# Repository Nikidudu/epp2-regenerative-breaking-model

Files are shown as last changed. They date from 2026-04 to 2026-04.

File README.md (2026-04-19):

# Regenerative Braking System

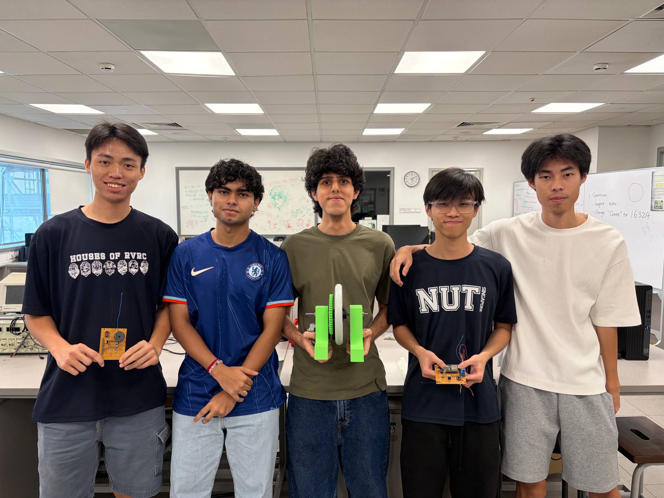
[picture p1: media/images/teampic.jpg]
Team Picture
 

## Overview
Regenerative braking is a key technology in electric vehicles that recovers kinetic energy during deceleration and converts it into usable electrical energy. Instead of dissipating energy as heat, this system improves overall efficiency, extends driving range, and reduces mechanical wear.

This project demonstrates a small-scale regenerative braking system that converts rotational kinetic energy into electrical energy using a DC motor as a generator, with energy stored for later use.

## Design Goals & Objectives
The objective of this project is to design a regenerative braking system capable of converting kinetic energy into electrical energy during deceleration and storing it efficiently. The system aims to achieve an energy recovery efficiency of at least 50%, operate within a 12–24V range, and safely manage current flow using a controlled power electronic interface. Additional goals include ensuring system safety, minimising energy losses, and maintaining reliable operation under repeated braking conditions.

## System Architecture
The system operates by switching a PMDC motor from motoring mode (electrical → mechanical) to generating mode (mechanical → electrical) during braking. The rotational inertia of the system drives the motor, producing electrical energy which is then conditioned and stored.

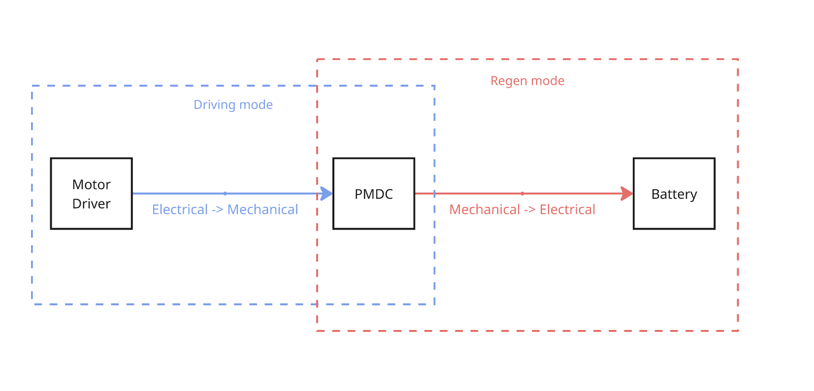
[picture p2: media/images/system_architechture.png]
System Architecture
 

## Mechanical Design
The mechanical system consists of a rotating wheel directly coupled to a PMDC motor. During braking, the kinetic energy of the rotating wheel is transferred to the motor shaft, causing it to act as a generator.

For detailed design and considerations:
- [Mechanical Design](docs/mechanical.md)

## Electrical Design
The electrical subsystem switches the motor from driving mode or regenerative mode. During driving mode, users may control the acceleration of the motor. During regenerative mode, the AC voltage is rectified and boosted into a capacitor for storage.

For full circuit design and explanation:
- [Electrical Design](docs/electrical.md)

## Software
A PID loop is used to control the PWM of the DC-DC converter, ensuring output voltage remains constant towards the battery. Other software include the swtiching mechanism and driving PWM.

- [Software Design](docs/software.md)

## Results
In Progress: The project aims to

- Measure energy saved from regenerative breaking
- Successfuly store energy in energy storing element
- Noticeable mechanical resistance corresponding to regenerative braking

Full Results:

- [Results and Analysis](docs/results.md)

## Final Project

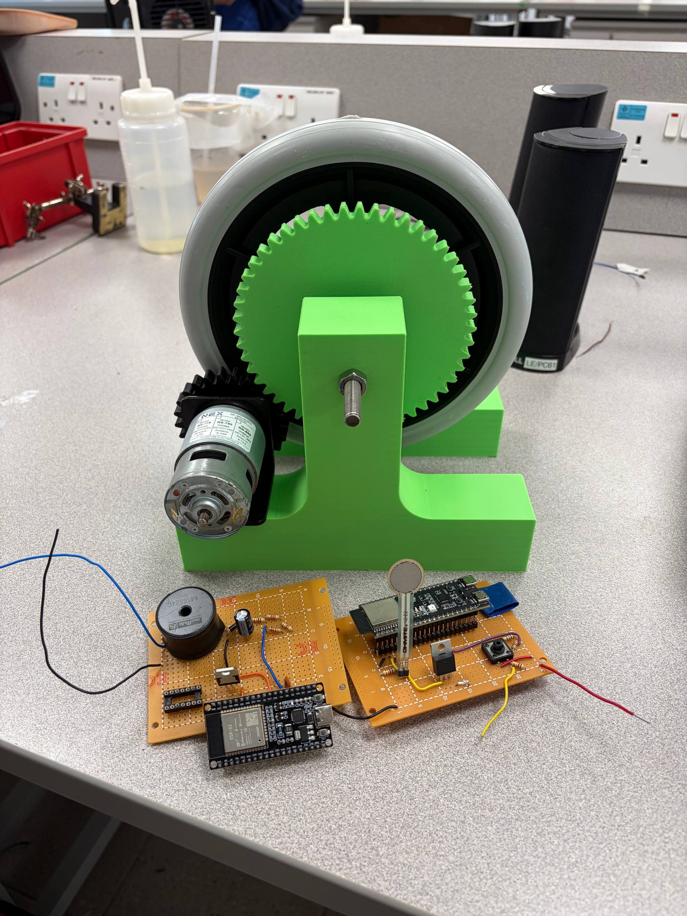
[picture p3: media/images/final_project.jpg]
final project
 

## Future Improvements

- Our system had some siginficant issues when connecting a low resistance load, namely the DC-DC converter will go into DCM mode, rendering our PID useless. A higher PWM freqency could be used to improve this.
- Our mechanical design was tested with 6V instead of the rated 12V, due to saftey concerns, a more stable build is needed to test with higher speeds.
- We had an issue with a wire burning up with no apparent reason, further analysis needed.
- There was a lack of noticable breaking of the wheel. The wheel span for 20 seconds without regen, and around 18 seconds with regen. This may be due to the use of a high resistance load, causing less current being able to flow.

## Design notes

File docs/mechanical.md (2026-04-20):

# Mechanical Design

## 1. Design Objectives

The mechanical system was designed to provide stable rotational support for the flywheel while enabling sufficient momentum to be stored in the wheel to observe regenerative breaking.

The key objectives were:
- To provide stable support for the rotating wheel  
- To minimise frictional losses during rotation  
- To ensure effective coupling between the wheel and generator  
- To reduce the speed of the wheel by using a correct gear ratio
- To allow enough momentum for a stable back emf to be produced.

## 2. Overall Design Description

The system consists of a rotating wheel mounted on a shaft, which is mechanically coupled to a motor acting as a generator. The generated electrical energy is then processed by the boost converter circuit.

Energy flow in the system can be summarised as:

**Mechanical Energy (wheel rotation) → Gear Reduction → Generator/Motor**

The wheel stores kinetic energy, which is partially recovered during regenerative braking when the generator applies an opposing torque.

## 3. Key Components and Design Choices

### 3.1 Flywheel

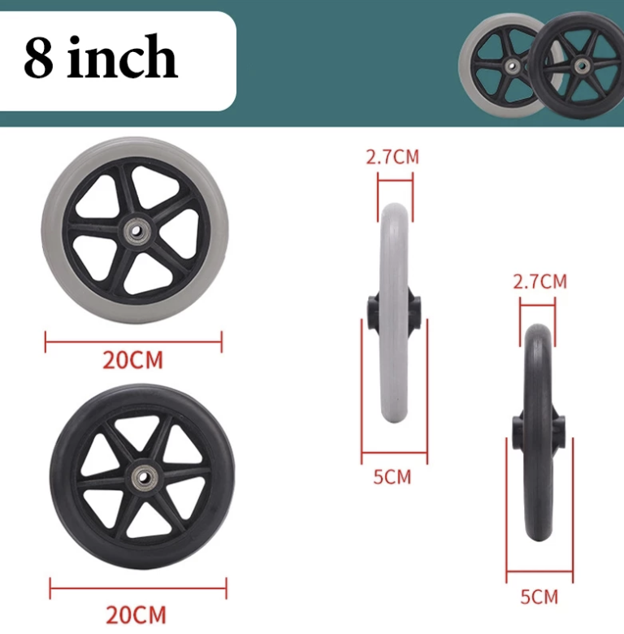
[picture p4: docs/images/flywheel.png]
flywheel


A 8-inch wheelchair wheel was used as the flywheel element in the system. The primary function of the flywheel is to store kinetic energy, which can then be converted into electrical energy during braking.

However, due to its relatively low mass, the flywheel has low rotational inertia. This limits the total amount of recoverable energy and reduces the observable effect of regenerative braking.

The wheel also came with a bearing attached to the centre bore, allowing for free motion between the shaft and wheel.

### 3.2 Shaft and Gears

shaft and gears

- The wheel is mounted onto a threaded rod that is locked in to the supports via 8 inch nuts.
- One gear is connected directly to the wheel, while the other is connected towards the motor. The gear ratio used is 1:2, with PLA material andpress fitted on the wheel and motor.
- A motor bracket was used to secure the motor into place, using 6mm threaded inserts and screws into the supports.

### 3.3 Structural Frame

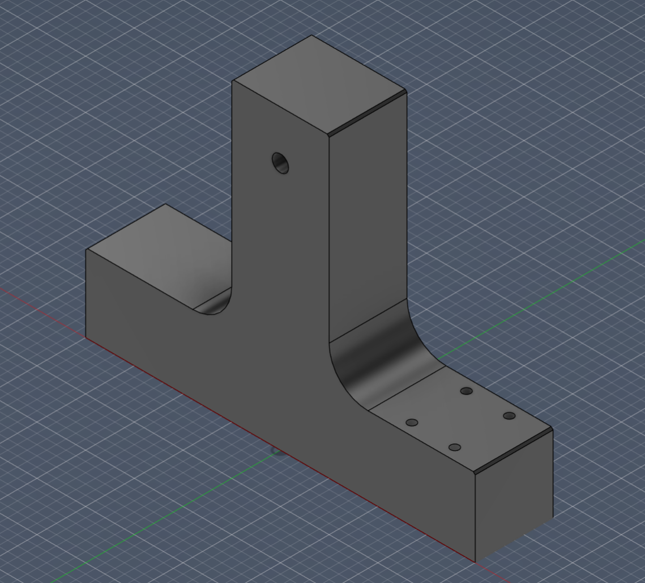
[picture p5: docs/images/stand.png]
stand


The structural frame was constructed using a PLA material and were fully 3d-printed. While sufficient for low-speed testing, the frame lacked rigidity. 

This resulted in:
- High vibrations at higher rotational speeds  
- Safety concerns when operating at the intended 12 V  
- Restriction of testing to 6 V operation  

## 4. System Performance Analysis

The mechanical design directly influenced the experimental results.

- The wheel spin time was observed to be approximately 20 seconds (without regenerative braking) this proved that there was minimal friction between the bearking and the supports, this allowed us to carry enough momentum and observe regenerative braking results if there were any.  
- The machine underwent heavy vibrating in higher RPMS. As a result, a human operator had to hold down the build while the wheel was spinning at high rpms, and we were capped at 6V operation.
- The gears fit nicely with each other, with no gear interfearence observed. However, loud sounds were produced due to using spur gears.

## 5. Limitations of Current Design

The current mechanical design has several limitations:

- **Low structural rigidity**, preventing safe high-speed operation  
- **Low flywheel inertia**, limiting energy storage capacity  
- **Higher friction losses** due to basic support structure  
- **Lack of safety enclosure**, restricting testing conditions  

These limitations contributed to the reduced performance observed in the system.

## 6. Improvements and Future Work

Several improvements can be made to enhance the mechanical performance:

- Use a **heavier flywheel** to increase rotational inertia and energy storage  
- Construct a **more rigid frame** (e.g., aluminium or reinforced structure)  
- Add a **protective enclosure** to enable safe high-speed testing  
- Ensure secure mounting of all components to minimise vibration  

These improvements would allow the system to operate at higher speeds and significantly enhance the effectiveness of regenerative braking.

## 7. Summary

The mechanical system successfully enabled rotational motion and energy transfer; however, its performance was limited by structural and design constraints.

While functional at low voltage, the design requires further refinement to achieve efficient and safe operation under higher loads, particularly for demonstrating effective regenerative braking.

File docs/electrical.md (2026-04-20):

# Electrical System

## 1. Design Objectives

The electrical system was designed to enable energy conversion, voltage regulation, and controlled regenerative braking.

The key objectives were:
- To convert mechanical energy into electrical energy using a generator  
- To regulate the generated voltage to a stable output of 6.6 V  
- To implement a closed-loop control system using a PID controller  
- To safely manage current and voltage within system limits  
- To interface with sensors and actuators for real-time control  

## 2. System Overview

The electrical system consists of two main subsystems:

1. **Acceleration and Braking Controller** – A system to control breaking and acceleration 
2. **Power Conversion** – A boost converter steps up and regulates the generated voltage with a closed-loop control.

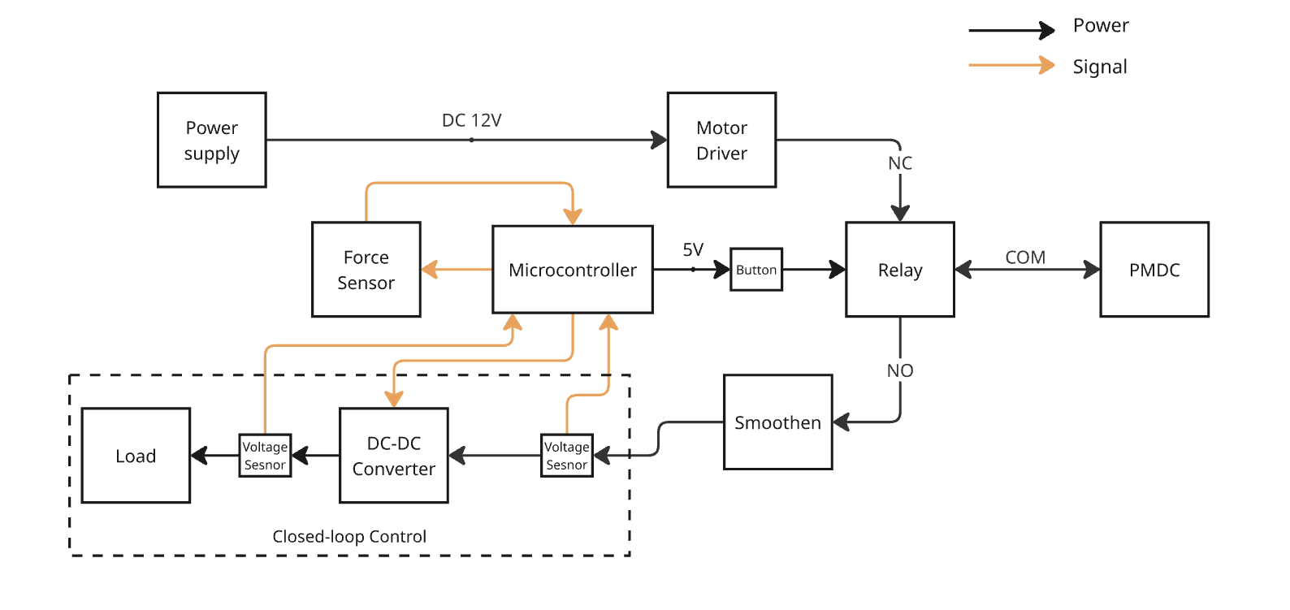
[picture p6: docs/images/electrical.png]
System Overview


## 3. Key Components and Design Choices

## 3.1 Acceleration and Braking Controller (SSM)

### 3.1.1 Generator/DC Motor

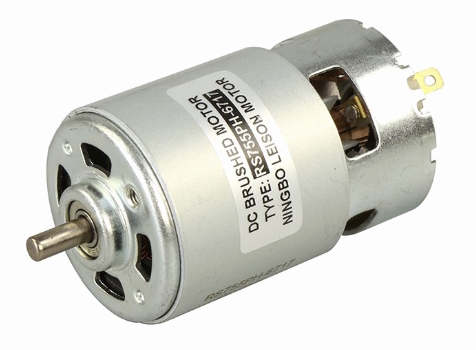
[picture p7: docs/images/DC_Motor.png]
DC motor


A RS-775-R 12V-24V DC motor is used as the generator and motor to convert rotational energy into electrical energy via electromagnetic induction and vice versa. The motor was chosen due to its high RPM capabilities with low torque.

Since generated voltage is proportional to rotational speed, this would be suitable as the high RPMs allow us to observe these effects greatly. 

This dependency directly affects the performance of the system, especially at lower operating voltages.

### 3.1.2 Force sensor

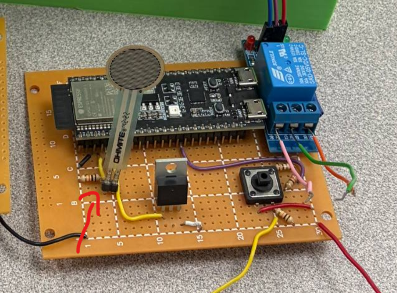
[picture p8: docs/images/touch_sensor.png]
force sensor


A Round Force Sensor (FSR402) was used to simulate the accalerator pedal in cars. It works by increasing the resistance as more force is applied. 

The connections are as follows:
- Connected to a 3.3V high output pin in the esp32
- Pulldown resistor on output to reduce noise and floating voltage
- Input to a standard GPIO analog pin

### 3.1.3 Relay and Button Switching

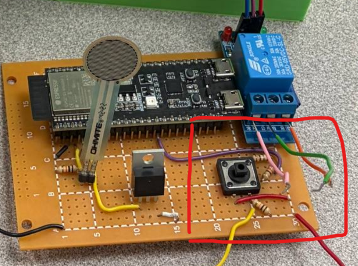
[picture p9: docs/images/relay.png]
relay


A standard relay with 5V switching was used to change between the modes of braking and non-braking. The relay switches to NO when the signal pin is put to ground, and NC otherwise.

The connections are as follows:
- The relay is grounded via a resistor to prevent current surge and floating voltages, this leaves the default state at NC, where this is in non-braking mode
- One end of the button is put to the 5V high from the arduino
- When the button is pressed, the signal wire from the relay is set to a 5V high, switching the relay circuit from non-braking to braking mode.
- A voltage devider is used to split the voltage of 5V to 3.3V to allow the button status to be read digitally as well

## 3.2 Power conversion

### 3.2.1 Boost Converter

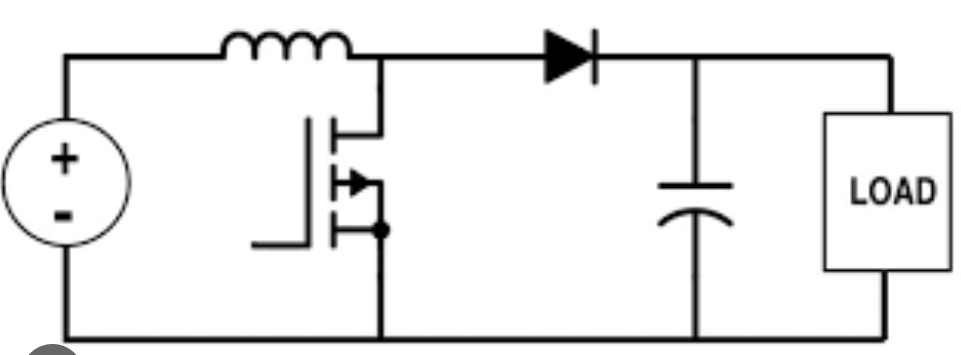
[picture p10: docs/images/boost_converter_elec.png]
boost converter


A standard boost converter was made to step up the variable input voltage from the generator to a stable output voltage.

The converter operates using:
- A MOSFET controlled by PWM  
- An inductor for energy storage  
- A diode and capacitor for output smoothing  

By adjusting the duty cycle of the PWM signal, the output voltage can be controlled.

### 3.2.2 Voltage Sensing (ADC System)

The ESP32 ADC operates in continuous sampling mode to measure:
- Output voltage (Vout)  
- Input voltage (Vin)  

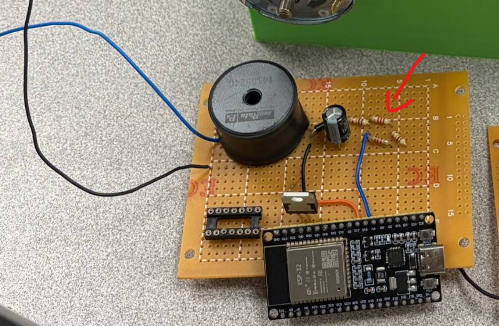
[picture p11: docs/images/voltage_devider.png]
voldev


To measure these voltages, a voltage divider was used to scale the voltage readings to the 3.3V analog input in the esp32.

Key features:
- High-frequency sampling (~50 kHz)  
- Averaging of multiple samples to reduce noise  
- Calibration using eFuse-based correction  
- Voltage divider scaling to measure higher voltages  

This enables accurate real-time feedback for the control system.

### 3.2.3 PWM Control (LEDC Module)

The ESP32 LEDC module generates a PWM signal to control the boost converter.

- Frequency: 4 kHz  
- Resolution: 13-bit  
- Duty cycle range: 0 to 7500  

The duty cycle determines how much energy is transferred through the converter:
- Higher duty cycle → higher output voltage  
- Lower duty cycle → lower output voltage  

## 4. Control System (PID Controller)

A PID controller is implemented to regulate the output voltage to a target of **6.6 V**.

The control law is:

- Proportional term responds to present error  
- Integral term accumulates past error  
- Derivative term predicts future error  

The controller continuously:
1. Measures output voltage  
2. Computes error relative to target  
3. Updates PID terms  
4. Adjusts PWM duty cycle  

## 5. System Behaviour and Performance

The system successfully maintained a stable output voltage of approximately **6.6 V for 15 seconds**, demonstrating effective closed-loop control.

However, performance was affected under certain conditions:

- When connected to a low-resistance load, the converter entered **Discontinuous Conduction Mode (DCM)**  
- In DCM, the system dynamics changed, reducing the effectiveness of the PID controller  
- This resulted in reduced stability and control accuracy  

Additionally:
- Limited input voltage (due to low rotational speed) restricted overall system performance  
- High resistance loads reduced current flow, limiting braking effectiveness  

## 6. Electrical Issues Encountered

### 6.1 DC-DC Converter Instability
The converter became unstable under heavy load conditions due to transition into DCM. This caused the PID controller to behave unpredictably.

### 6.2 Wire Overheating
A wire was observed to burn during operation, indicating excessive current or insufficient wire rating.

Possible causes include:
- Undersized wire gauge  
- Lack of current limiting  
- Unexpected current spikes  

### 6.3 Limited Power Transfer
The system exhibited limited braking performance due to low current flow, which reduced electromagnetic braking torque.

## 7. Limitations of Current Design

- Operation limited to **6 V instead of 12 V**  
- PID tuning not optimised for different operating modes (CCM vs DCM)  
- Lack of current protection mechanisms  
- Inefficient power transfer under certain load conditions  
- Limited switching frequency affecting converter performance  

## 8. Improvements and Future Work

- Increase PWM switching frequency to reduce DCM operation  
- Implement **current sensing and protection** (e.g., shunt resistor, fuse)  
- Optimise PID tuning for different operating conditions  
- Improve component selection (MOSFET, inductor, wiring) for higher current handling  
- Enable safe operation at **12 V** to improve performance  
- Add filtering or compensation to improve stability  

## 9. Summary

The electrical system successfully demonstrated energy conversion and voltage regulation using a closed-loop control system.

While stable voltage output was achieved, performance was limited by converter dynamics, load conditions, and hardware constraints. Further optimisation of both control and hardware design is required to fully realise effective regenerative braking.

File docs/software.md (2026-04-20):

# Software

The software portion of this project can be divided into two main components:

- Small State Machine (User Input & System Control)
- Boost Converter Feedback Loop (Voltage Regulation)

## Small State Machine

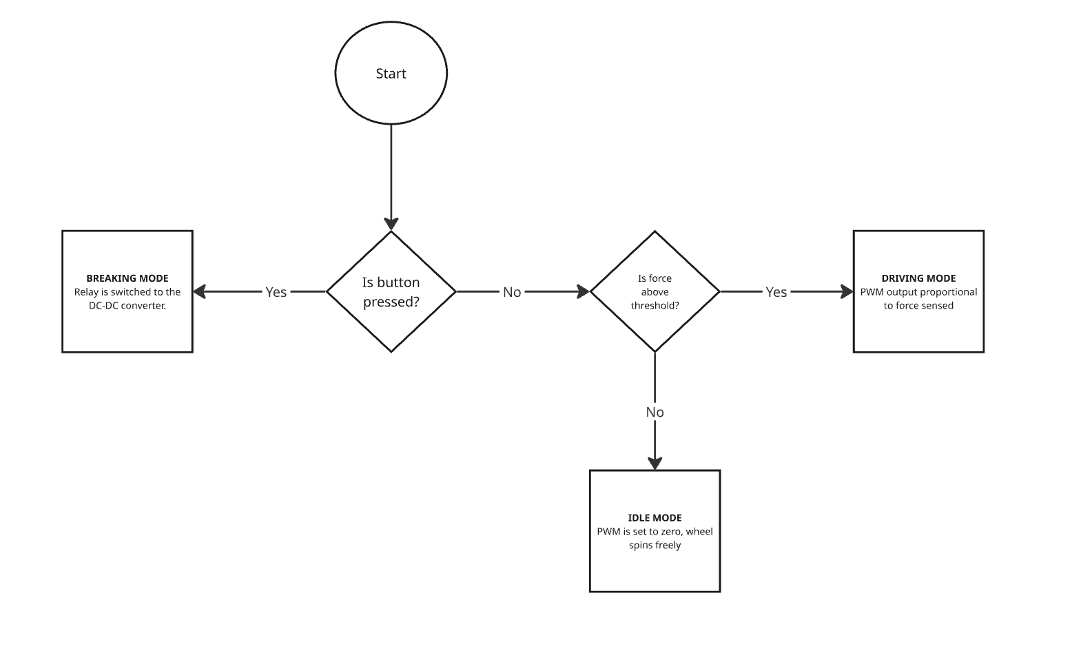
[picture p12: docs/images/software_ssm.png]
ssm


The small state machine is responsible for controlling when regenerative braking is active, based on user input and force detection.

A force sensor is continuously read using the ADC, and its value is mapped to a PWM signal. This PWM signal controls the level of braking applied.

A button input is used to toggle the braking system:
- When the button is pressed, braking is **disabled**
- When the button is not pressed, braking is **enabled**

The system operates in three main states:

1. **Driving and Acceleration**
    - Activated when the measured force is above the predefined threshold and active breaking is not enabled
    - PWM is proportional to force applied on sensor
    - The system accelerates

2. **Idle / No Braking**
   - Activated when the measured force is below a predefined threshold and active braking is not enabled  
   - PWM output is set to 0 
   - The system does not apply any braking force 

3. **Active Braking**
   - Activated when the button is pressed, regardless of the force sensor input
   - PWM output is set to zero
   - A relay and digital output are activated to engage the braking circuitry into the boost converter

This simple logic ensures that braking only occurs when required, preventing unnecessary energy dissipation and improving system control.

## Boost Converter Feedback Loop

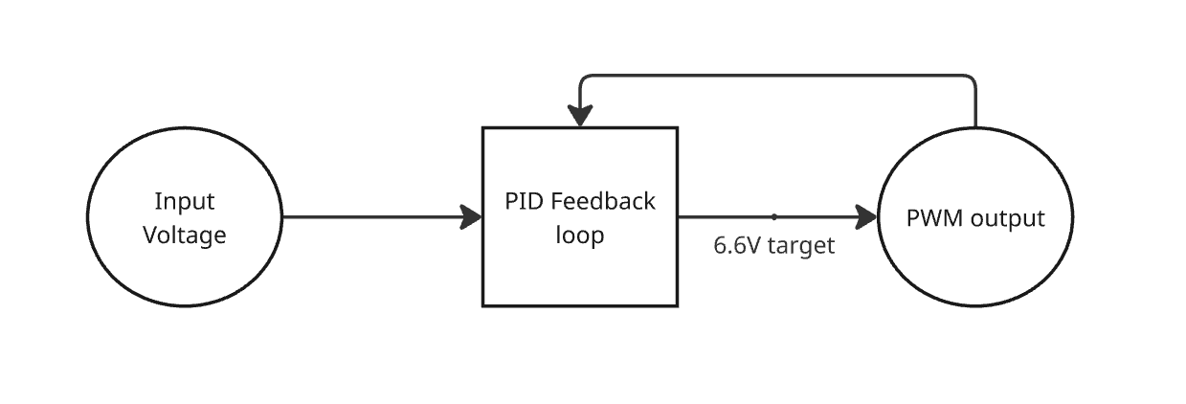
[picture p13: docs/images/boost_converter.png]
boost


The boost converter feedback loop is implemented on the ESP32 using a PID controller to regulate the output voltage.

### Signal Acquisition
- Two ADC channels are used:
  - One measures the **output voltage (Vout)**
  - One measures the **input voltage (Vin)**
- The ADC operates in continuous sampling mode at high frequency
- Raw ADC values are averaged and calibrated to obtain accurate voltage readings
- A voltage divider scaling factor is applied to reconstruct the actual voltage

### PID Control System

The system regulates the output voltage to a target of **6.6 V** using a PID controller.

- **Proportional term (P):** Responds to instantaneous voltage error  
- **Integral term (I):** Accumulates past error to eliminate steady-state offset  
- **Derivative term (D):** Predicts future error based on rate of change  

The control loop performs the following steps:
1. Measure output voltage  
2. Compute error between measured voltage and target voltage  
3. Update PID terms (with integral windup limiting)  
4. Adjust PWM duty cycle accordingly  

The PWM signal is generated using the ESP32 LEDC module and drives the boost converter switching element.

### Control Features and Safeguards

- **Integral windup protection:** Limits the integral term to prevent instability  
- **Duty cycle clamping:** Ensures PWM stays within safe bounds  
- **Noise floor handling:** Resets control when voltage is too low  
- **Dynamic timestep (dt):** Improves accuracy of derivative and integral calculations  

### System Behaviour

- When output voltage is below 6.6 V, the controller increases PWM duty cycle to boost voltage  
- When output voltage exceeds 6.6 V, the controller reduces duty cycle  
- The system continuously adjusts in real time to maintain a stable output voltage  

## Summary

The software integrates a high-level control system (state machine) with a low-level control loop (PID-regulated boost converter).  

- The **state machine** determines *when* braking should occur  
- The **PID controller** determines *how much* energy is transferred and regulates voltage  

Together, they enable controlled and stable regenerative braking operation.

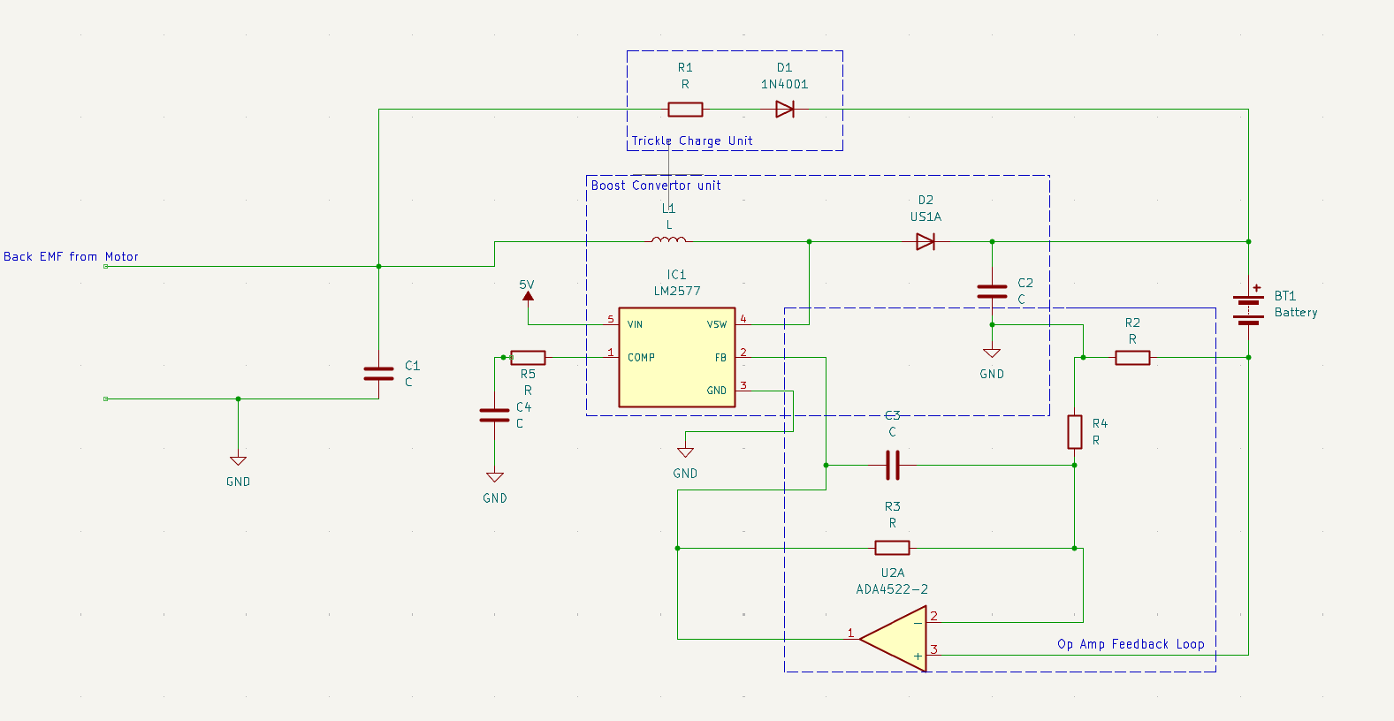
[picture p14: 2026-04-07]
hardware/electrical/images/Img_Paper_Design_Charging_Unit.png

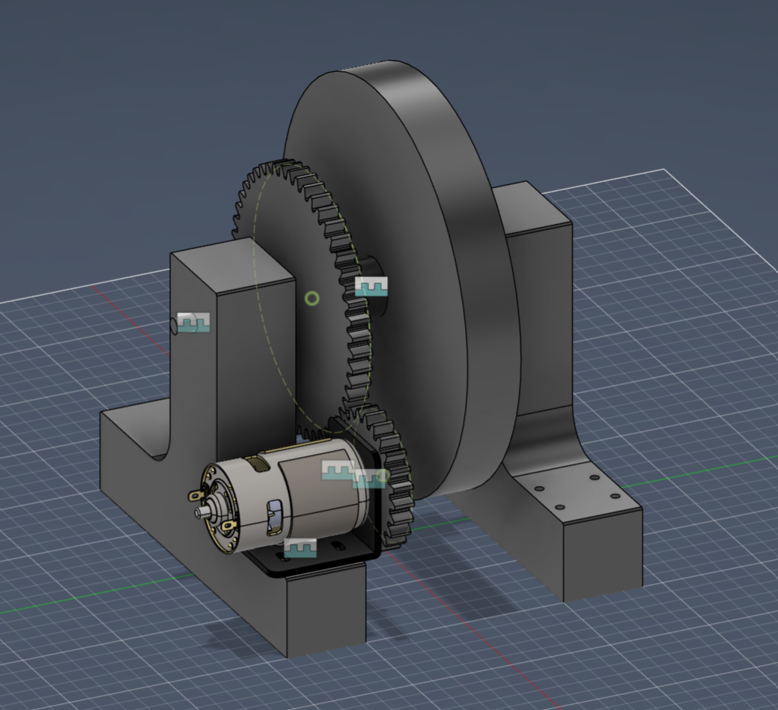
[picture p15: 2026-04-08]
hardware/mechanical/images/final_assemby_CAD.png

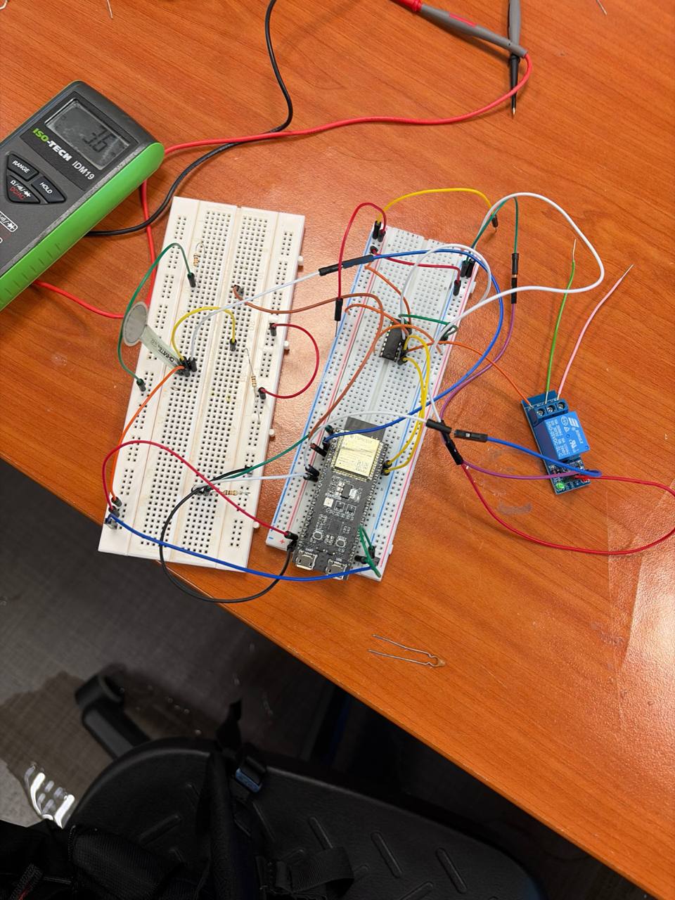
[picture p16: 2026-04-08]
hardware/electrical/images/accelerator_and_relay.jpg

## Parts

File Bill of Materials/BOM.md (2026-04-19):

| Item | Quantity | Price |
| ---- | --- | ----- |
|  RS-775-R DC Motor | 1 | 11.54 |
| Bracket for motor	| 1 | 5.51 |
| Stainless Steel Threaded Rod Screw | 1 | 7.33 |
| 8 inch wheel | 1 | 9.9 |
|  | **Total** | **34.28** |

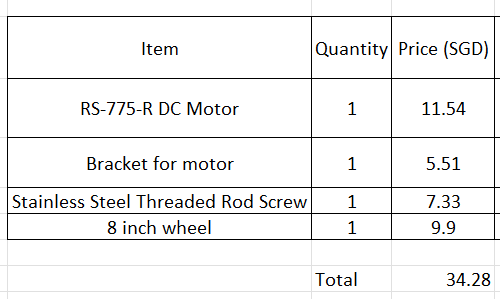
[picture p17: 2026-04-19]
Bill of Materials/BOM.png

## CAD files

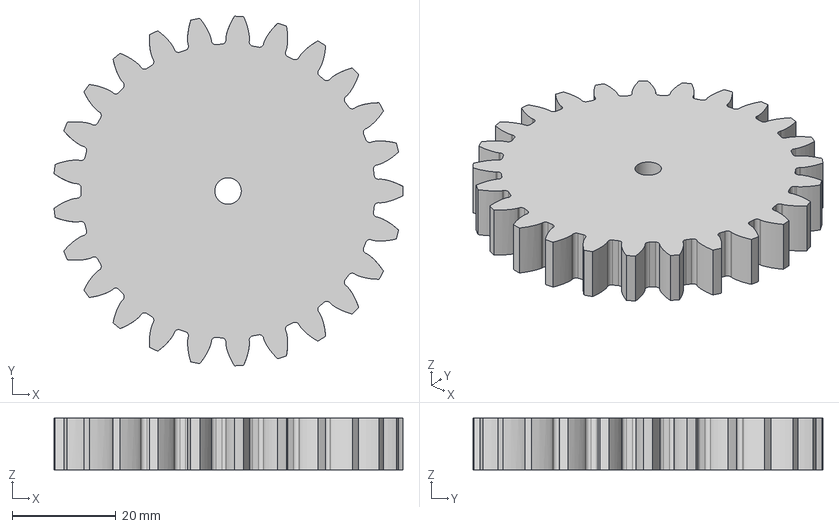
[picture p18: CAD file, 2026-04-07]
hardware/mechanical/cad/smallgeartight.step
67.3 x 67.5 x 10.0 mm

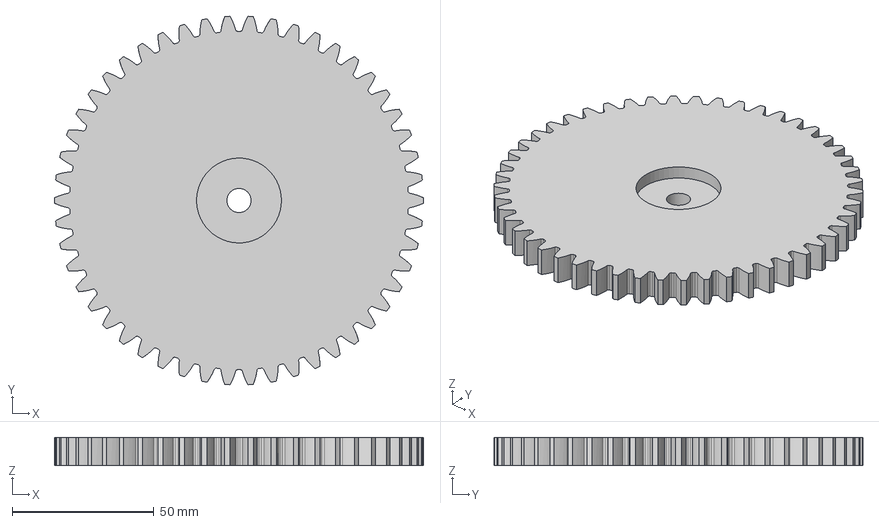
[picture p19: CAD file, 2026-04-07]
hardware/mechanical/cad/Gear BIG2.step
130.0 x 129.9 x 10.0 mm

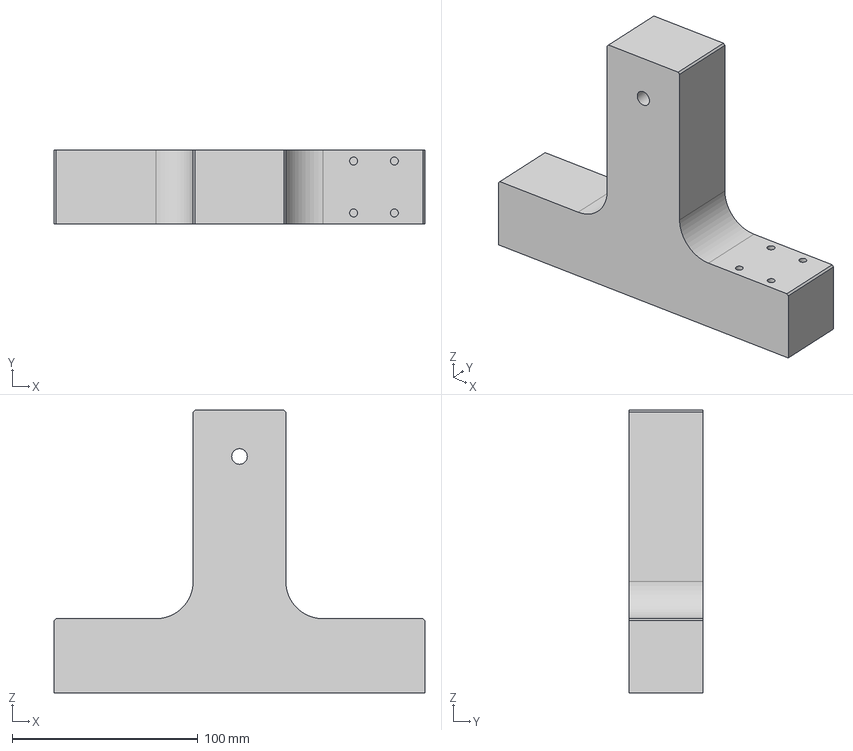
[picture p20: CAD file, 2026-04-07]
hardware/mechanical/cad/Stand 2.step
200.0 x 40.0 x 152.4 mm

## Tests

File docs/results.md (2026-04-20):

# Results and Analysis

## 1. Overview of Results
The prototype demonstrated successful operation, maintaining a steady back voltage of **6.6 V** for approximately **15 seconds** under controlled conditions. This indicates that the regenerative system is capable of stable energy conversion within the tested parameters.

## 2. Key Experimental Results
- The system maintained a back steady back voltage of **6.6 V for 15 seconds**
- Without regenerative braking, the wheel spun for approximately **20 seconds**
- With regenerative braking, the wheel spun for approximately **18 seconds**
- Testing was conducted at **6 V instead of the rated 12 V** due to safety concerns
- PID was tuned sufficiently until no oscilation was found from the varying back voltage.

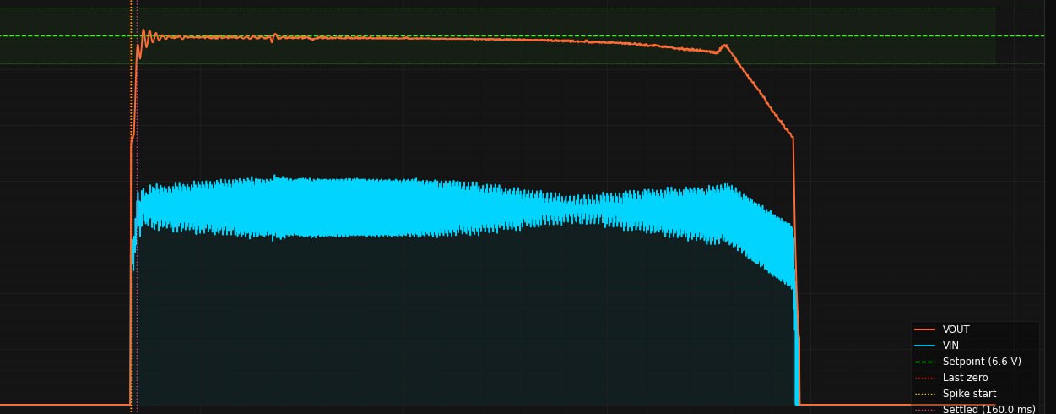
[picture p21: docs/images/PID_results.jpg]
PID results


## 3. Analysis of System Performance
The relatively small reduction in wheel spin time (from 20 s to 18 s) suggests that the regenerative braking effect was minimal. This is likely due to the use of a **high-resistance load**, which limited current flow and therefore reduced the electromagnetic braking torque.

Additionally, operating the system at **6 V instead of 12 V** reduced the rotational speed and back EMF generated, further limiting the observable performance of the regenerative braking system.

## 4. Identified Issues and Technical Explanation

### 4.1 DC-DC Converter Instability
When connected to a low-resistance load, the DC-DC converter entered **Discontinuous Conduction Mode (DCM)**, rendering the PID controller ineffective. This occurs because the system dynamics change significantly in DCM, making the existing PID tuning unsuitable. Increasing the PWM switching frequency could help maintain **Continuous Conduction Mode (CCM)** and improve system stability.

### 4.2 Mechanical Limitations
The system was only tested at **6 V** due to safety concerns regarding the structural integrity of the setup. At this lower voltage, the system operates at reduced speed, limiting both energy generation and braking performance. A more robust mechanical design is required to safely test the system at its intended **12 V operating condition**.

### 4.3 Electrical Fault (Wire Overheating)
A wire was observed to burn during operation, indicating a possible **overcurrent condition** or insufficient wire gauge. This suggests that the current exceeded safe limits, highlighting the need for proper current rating calculations and protective components such as **fuses or current limiting mechanisms**.

### 4.4 Limited Braking Effect
The minimal difference in stopping time indicates weak regenerative braking performance. This is likely due to the **high-resistance load**, which restricts current flow. Since braking torque is proportional to current, increasing current flow (e.g., by reducing load resistance or improving power handling capability) would result in stronger braking.

## 5. Evaluation Against Objectives
While the system successfully demonstrated **voltage regulation**, it did not achieve significant braking performance. This suggests that the electrical control aspect of the system is functional, but further optimisation of load conditions, control strategy, and mechanical design is required to fully achieve the objectives of effective regenerative braking.

## 6. Improvements and Future Work
- Increase PWM switching frequency to reduce the likelihood of DCM operation  
- Redesign the mechanical structure to safely support **12 V testing**  
- Use appropriately rated wires and implement **overcurrent protection**  
- Optimise load resistance to allow higher current flow and improve braking torque  
- Retune the PID controller for different operating modes (CCM vs DCM)

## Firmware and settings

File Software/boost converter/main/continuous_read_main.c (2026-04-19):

/*
 * SPDX-FileCopyrightText: 2021-2022 Espressif Systems (Shanghai) CO LTD
 *
 * SPDX-License-Identifier: Apache-2.0
 */
#include "esp_adc/adc_cali.h"
#include "esp_adc/adc_cali_scheme.h"
#include <string.h>
#include <stdio.h>
#include "sdkconfig.h"
#include "esp_log.h"
#include "freertos/FreeRTOS.h"
#include "esp_err.h"
#include "driver/ledc.h"
#include "esp_timer.h"
#include "freertos/task.h"
#include <math.h>
#include "freertos/semphr.h"
#include "esp_adc/adc_continuous.h"

#define EXAMPLE_ADC_UNIT                    ADC_UNIT_1  
#define _EXAMPLE_ADC_UNIT_STR(unit)         #unit
#define EXAMPLE_ADC_UNIT_STR(unit)          _EXAMPLE_ADC_UNIT_STR(unit)
#define EXAMPLE_ADC_CONV_MODE               ADC_CONV_SINGLE_UNIT_1
#define EXAMPLE_ADC_ATTEN                   ADC_ATTEN_DB_12
#define EXAMPLE_ADC_BIT_WIDTH               SOC_ADC_DIGI_MAX_BITWIDTH

#if CONFIG_IDF_TARGET_ESP32 || CONFIG_IDF_TARGET_ESP32S2
#define EXAMPLE_ADC_OUTPUT_TYPE             ADC_DIGI_OUTPUT_FORMAT_TYPE1
#define EXAMPLE_ADC_GET_CHANNEL(p_data)     ((p_data)->type1.channel)
#define EXAMPLE_ADC_GET_DATA(p_data)        ((p_data)->type1.data)
#else
#define EXAMPLE_ADC_OUTPUT_TYPE             ADC_DIGI_OUTPUT_FORMAT_TYPE2
#define EXAMPLE_ADC_GET_CHANNEL(p_data)     ((p_data)->type2.channel)
#define EXAMPLE_ADC_GET_DATA(p_data)        ((p_data)->type2.data)
#endif
#define ADC_NOISE_FLOOR_MV  200
#define EXAMPLE_READ_LEN                    256
/*pwm config */
#define LEDC_TIMER              LEDC_TIMER_0
#define LEDC_MODE               LEDC_HIGH_SPEED_MODE
#define LEDC_OUTPUT_IO          25 // Define the output GPIO
#define LEDC_CHANNEL            LEDC_CHANNEL_0
#define LEDC_DUTY_RES           LEDC_TIMER_13_BIT // Set duty resolution to 13 bits
#define LEDC_DUTY               (4096) // Set duty to 50%. (2 ** 13) * 50% = 4096
#define LEDC_FREQUENCY          (4000) // Frequency in Hertz. Set frequency at 4 kHz

#define SMALL_RESISTANCE 2200
#define BIG_RESISTANCE 10000
                
#define i_limit  1.0f // Integral windup limit based on max duty cycle and Ki
#define PID_KP        56.0f
#define PID_KI        1.0f
#define PID_KD        2.67f
#define VOUT  6.6f      // Volts
#define DUTY_MAX        7500.0f
#define DUTY_MIN        0.0f

#if CONFIG_IDF_TARGET_ESP32
static adc_channel_t channel[2] = {ADC_CHANNEL_6, ADC_CHANNEL_7}; //GPIO 34, 35
#else
static adc_channel_t channel[2] = {ADC_CHANNEL_2, ADC_CHANNEL_3};
#endif

static TaskHandle_t s_task_handle;
static const char* TAG = "EXAMPLE";
static adc_cali_handle_t cali_handle = NULL;

static void example_ledc_init(void)
{
    // Prepare and then apply the LEDC PWM timer configuration
    ledc_timer_config_t ledc_timer = {
        .speed_mode       = LEDC_MODE,
        .duty_resolution  = LEDC_DUTY_RES,
        .timer_num        = LEDC_TIMER,
        .freq_hz          = LEDC_FREQUENCY,  // Set output frequency at 4 kHz
        .clk_cfg          = LEDC_AUTO_CLK
    };
    ESP_ERROR_CHECK(ledc_timer_config(&ledc_timer));

    // Prepare and then apply the LEDC PWM channel configuration
    ledc_channel_config_t ledc_channel = {
        .speed_mode     = LEDC_MODE,
        .channel        = LEDC_CHANNEL,
        .timer_sel      = LEDC_TIMER,
        .intr_type      = LEDC_INTR_DISABLE,
        .gpio_num       = LEDC_OUTPUT_IO,
        .duty           = 0, // Set duty to 0%
        .hpoint         = 0
    };
    ESP_ERROR_CHECK(ledc_channel_config(&ledc_channel));
}

static bool IRAM_ATTR s_conv_done_cb(adc_continuous_handle_t handle, const adc_continuous_evt_data_t *edata, void *user_data)
{
    BaseType_t mustYield = pdFALSE;
    //Notify that ADC continuous driver has done enough number of conversions
    vTaskNotifyGiveFromISR(s_task_handle, &mustYield);

    return (mustYield == pdTRUE);
}

static void continuous_adc_init(adc_channel_t *channel, uint8_t channel_num, adc_continuous_handle_t *out_handle)
{
    adc_continuous_handle_t handle = NULL;

    adc_continuous_handle_cfg_t adc_config = {
        .max_store_buf_size = 1024,
        .conv_frame_size = EXAMPLE_READ_LEN,
    };
    ESP_ERROR_CHECK(adc_continuous_new_handle(&adc_config, &handle));

    adc_continuous_config_t dig_cfg = {
        .sample_freq_hz = 50 * 1000,
        .conv_mode = EXAMPLE_ADC_CONV_MODE,
        .format = EXAMPLE_ADC_OUTPUT_TYPE,
    };

    adc_digi_pattern_config_t adc_pattern[SOC_ADC_PATT_LEN_MAX] = {0};
    dig_cfg.pattern_num = channel_num;
    for (int i = 0; i < channel_num; i++) {
        adc_pattern[i].atten = EXAMPLE_ADC_ATTEN;
        adc_pattern[i].channel = channel[i] & 0x7;
        adc_pattern[i].unit = EXAMPLE_ADC_UNIT;
        adc_pattern[i].bit_width = EXAMPLE_ADC_BIT_WIDTH;

        ESP_LOGI(TAG, "adc_pattern[%d].atten is :%"PRIx8, i, adc_pattern[i].atten);
        ESP_LOGI(TAG, "adc_pattern[%d].channel is :%"PRIx8, i, adc_pattern[i].channel);
        ESP_LOGI(TAG, "adc_pattern[%d].unit is :%"PRIx8, i, adc_pattern[i].unit);
    }
    dig_cfg.adc_pattern = adc_pattern;
    ESP_ERROR_CHECK(adc_continuous_config(handle, &dig_cfg));

    *out_handle = handle;
}

void app_main(void)
{   
    float parallel_voltage_pd_multiplier = (float)(SMALL_RESISTANCE + BIG_RESISTANCE) / SMALL_RESISTANCE; // Calculate the multiplier for parallel voltage measurement
    esp_err_t ret;
   // esp_log_set_vprintf(NULL);
    uint32_t ret_num = 0;

    uint8_t result[EXAMPLE_READ_LEN] = {0};

    float Voutput = VOUT;

    memset(result, 0xcc, EXAMPLE_READ_LEN);

    adc_cali_line_fitting_config_t cali_config = {
        .unit_id = EXAMPLE_ADC_UNIT,
        .atten = EXAMPLE_ADC_ATTEN,
        .bitwidth = EXAMPLE_ADC_BIT_WIDTH,
    };

    float pid_integral   = 0.0f;
    float pid_prev_measurement = 0.0f;
    float dt = 0.001f;
    int   targetDutyCycle           = 0;
    int64_t last_loop_time = esp_timer_get_time();
    int64_t current_time;

    example_ledc_init();
    esp_err_t retefuse = adc_cali_create_scheme_line_fitting(&cali_config, &cali_handle);
    if (retefuse == ESP_OK) {
        ESP_LOGI(TAG, "Calibration Success!");
    } else {
        ESP_LOGW(TAG, "Calibration not supported or eFuse not burnt.");
    }
    s_task_handle = xTaskGetCurrentTaskHandle();

    adc_continuous_handle_t handle = NULL;
    continuous_adc_init(channel, sizeof(channel) / sizeof(adc_channel_t), &handle);

    adc_continuous_evt_cbs_t cbs = {
        .on_conv_done = s_conv_done_cb,
    };
    ESP_ERROR_CHECK(adc_continuous_register_event_callbacks(handle, &cbs, NULL));
    ESP_ERROR_CHECK(adc_continuous_start(handle));
    ESP_LOGI(TAG, "i_limit: %.2f", i_limit);
    uint32_t sum_raw_ch6 = 0;
    uint32_t sum_raw_ch7 = 0;
    while (1) {

        /**
         * This is to show you the way to use the ADC continuous mode driver event callback.
         * This `ulTaskNotifyTake` will block when the data processing in the task is fast.
         * However in this example, the data processing (print) is slow, so you barely block here.
         *
         * Without using this event callback (to notify this task), you can still just call
         * `adc_continuous_read()` here in a loop, with/without a certain block timeout.
         */
        ulTaskNotifyTake(pdTRUE, portMAX_DELAY);

       // char unit[] = EXAMPLE_ADC_UNIT_STR(EXAMPLE_ADC_UNIT);

        while (1) {
            ret = adc_continuous_read(handle, result, EXAMPLE_READ_LEN, &ret_num, 0);
            if (ret == ESP_OK) {
                uint32_t sum_raw_ch6 = 0;   // moved inside, removed stale sum_raw
                uint32_t sum_raw_ch7 = 0;

                current_time = esp_timer_get_time();
                dt = (current_time - last_loop_time) / 1000000.0f;
                last_loop_time = current_time;
                int sample_count_ch6 = 0;
                int sample_count_ch7 = 0;
                int calibrated_voltage     = 0;
                int calibrated_voltage_ch7 = 0;

                for (int i = 0; i < ret_num; i += SOC_ADC_DIGI_RESULT_BYTES) {
                    adc_digi_output_data_t *p = (adc_digi_output_data_t*)&result[i];
                    uint8_t ch = EXAMPLE_ADC_GET_CHANNEL(p);

                    if (ch == channel[0]) {
                        sum_raw_ch6 += EXAMPLE_ADC_GET_DATA(p);
                        sample_count_ch6++;
                    } else if (ch == channel[1]) {
                        sum_raw_ch7 += EXAMPLE_ADC_GET_DATA(p);
                        sample_count_ch7++;
                    }
                }
                if (sample_count_ch6 > 0) {
                    adc_cali_raw_to_voltage(cali_handle, sum_raw_ch6 / sample_count_ch6, &calibrated_voltage);
                }
                if (sample_count_ch7 > 0) {
                    adc_cali_raw_to_voltage(cali_handle, sum_raw_ch7 / sample_count_ch7, &calibrated_voltage_ch7);
                }

                float node_voltage;
                float input_voltage;
                float pid_output;
               // float targetDutyCycle;
                if (calibrated_voltage < ADC_NOISE_FLOOR_MV) {
                    calibrated_voltage = 0;
                    node_voltage = 0.0f;
                    pid_integral = 0.0f; // Reset integral term if voltage is at noise floor
                    pid_prev_measurement = 0.0f; // Reset previous measurement
                    targetDutyCycle = 0; // Set to max duty cycle to try to increase voltage
                    pid_output = 0.0f;

                } else {
                    node_voltage = ((calibrated_voltage ) * parallel_voltage_pd_multiplier / 1000.0);
                    float error = Voutput - node_voltage;
                    pid_integral += error * dt;
                    
                    if (pid_integral >  i_limit) pid_integral =  i_limit;
                    if (pid_integral < -i_limit) pid_integral = -i_limit;
                    
                    float derivative = (pid_prev_measurement - node_voltage) / dt;
                    pid_prev_measurement = node_voltage;
                    pid_output     = PID_KP * error + PID_KI * pid_integral + PID_KD * derivative;
                    targetDutyCycle += pid_output;
                    if (targetDutyCycle > DUTY_MAX) targetDutyCycle = DUTY_MAX;
                    if (targetDutyCycle < DUTY_MIN) targetDutyCycle = DUTY_MIN;



                    //targetDutyCycle = round((1.0-(node_voltage / Voutput))*8191.0); // Calculate duty cycle based on voltage
                    
                }
                input_voltage = (calibrated_voltage_ch7 < ADC_NOISE_FLOOR_MV)? 0.0f   : (calibrated_voltage_ch7 * parallel_voltage_pd_multiplier / 1000.0f);
                                   
                ESP_ERROR_CHECK(ledc_set_duty(LEDC_MODE, LEDC_CHANNEL, (int)targetDutyCycle)); 
                ESP_ERROR_CHECK(ledc_update_duty(LEDC_MODE, LEDC_CHANNEL));
               // ESP_LOGI(TAG, "Calibrated Voltage: %d mV , Node Voltage: %.2f V, with PWM Duty Cycle: %d", calibrated_voltage, node_voltage, targetDutyCycle);
                ESP_LOGI(TAG, "TIME: %"PRIu64" VIN: %.2f V, VOUT: %.2f V, PWM: %d, PID: %.2f, I: %.2f",current_time, input_voltage, node_voltage, (int)targetDutyCycle, pid_output, pid_integral);
               vTaskDelay(1);
            } else if (ret == ESP_ERR_TIMEOUT) {
                //We try to read `EXAMPLE_READ_LEN` until API returns timeout, which means there's no available data
                break;
            }
        }
    }

    ESP_ERROR_CHECK(adc_continuous_stop(handle));
    ESP_ERROR_CHECK(adc_continuous_deinit(handle));
}

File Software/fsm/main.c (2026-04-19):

#include <stdio.h>
#include <string.h>
#include "freertos/FreeRTOS.h"
#include "freertos/task.h"
#include "driver/gpio.h"
#include "driver/ledc.h"
#include "esp_adc/adc_oneshot.h"
#include "esp_adc/adc_cali.h"
#include "esp_adc/adc_cali_scheme.h"
#include "esp_log.h"

/* ── Pin definitions ───────────────────────────────────────────────── */
#define FORCE_SENSOR_PIN    ADC_CHANNEL_3   // GPIO4  on ESP32 = ADC1_CH3
#define PWM_OUTPUT_PIN      2               // GPIO2
#define DIGITAL_OUT_PIN     1               // GPIO1
#define BUTTON_OUT_PIN      18              // GPIO18
#define BUTTON_IN_PIN       17              // GPIO17
#define RELAY_PIN           16              // GPIO16

/* ── Thresholds / constants ────────────────────────────────────────── */
#define FORCE_THRESHOLD     1000            // raw ADC counts (0–4095)
#define ADC_MAX_RAW         4095
#define PWM_MAX_DUTY        255             // 8-bit PWM  (0–255)

/* ── LEDC (PWM) config ─────────────────────────────────────────────── */
#define LEDC_TIMER          LEDC_TIMER_0
#define LEDC_MODE           LEDC_LOW_SPEED_MODE
#define LEDC_CHANNEL        LEDC_CHANNEL_0
#define LEDC_DUTY_RES       LEDC_TIMER_8_BIT   // 8-bit → 0-255
#define LEDC_FREQUENCY      5000                // 5 kHz

static const char *TAG = "FORCE_CTRL";

/* ──────────────────────────────────────────────────────────────────── */
/*  Helpers                                                             */
/* ──────────────────────────────────────────────────────────────────── */

/** Linear map, identical to Arduino map() */
static inline int map_value(int x, int in_min, int in_max, int out_min, int out_max)
{
    return (x - in_min) * (out_max - out_min) / (in_max - in_min) + out_min;
}

/** Clamp an int between lo and hi */
static inline int constrain_value(int x, int lo, int hi)
{
    if (x < lo) return lo;
    if (x > hi) return hi;
    return x;
}

/* ──────────────────────────────────────────────────────────────────── */
/*  Peripheral initialisation                                           */
/* ──────────────────────────────────────────────────────────────────── */

static void gpio_init(void)
{
    /* outputs */
    gpio_config_t out_cfg = {
        .pin_bit_mask = (1ULL << DIGITAL_OUT_PIN) |
                        (1ULL << BUTTON_OUT_PIN)  |
                        (1ULL << RELAY_PIN),
        .mode         = GPIO_MODE_OUTPUT,
        .pull_up_en   = GPIO_PULLUP_DISABLE,
        .pull_down_en = GPIO_PULLDOWN_DISABLE,
        .intr_type    = GPIO_INTR_DISABLE,
    };
    gpio_config(&out_cfg);

    /* inputs */
    gpio_config_t in_cfg = {
        .pin_bit_mask = (1ULL << BUTTON_IN_PIN),
        .mode         = GPIO_MODE_INPUT,
        .pull_up_en   = GPIO_PULLUP_DISABLE,
        .pull_down_en = GPIO_PULLDOWN_DISABLE,
        .intr_type    = GPIO_INTR_DISABLE,
    };
    gpio_config(&in_cfg);

    /* match Arduino setup() initial states */
    gpio_set_level(DIGITAL_OUT_PIN, 0);   // LOW
    gpio_set_level(BUTTON_OUT_PIN,  1);   // HIGH
    gpio_set_level(RELAY_PIN,       1);   // HIGH
}

static void ledc_pwm_init(void)
{
    ledc_timer_config_t timer = {
        .speed_mode      = LEDC_MODE,
        .duty_resolution = LEDC_DUTY_RES,
        .timer_num       = LEDC_TIMER,
        .freq_hz         = LEDC_FREQUENCY,
        .clk_cfg         = LEDC_AUTO_CLK,
    };
    ESP_ERROR_CHECK(ledc_timer_config(&timer));

    ledc_channel_config_t ch = {
        .speed_mode = LEDC_MODE,
        .channel    = LEDC_CHANNEL,
        .timer_sel  = LEDC_TIMER,
        .intr_type  = LEDC_INTR_DISABLE,
        .gpio_num   = PWM_OUTPUT_PIN,
        .duty       = 0,
        .hpoint     = 0,
    };
    ESP_ERROR_CHECK(ledc_channel_config(&ch));
}

static adc_oneshot_unit_handle_t adc_init(void)
{
    adc_oneshot_unit_handle_t handle;

    adc_oneshot_unit_init_cfg_t unit_cfg = {
        .unit_id  = ADC_UNIT_1,
        .ulp_mode = ADC_ULP_MODE_DISABLE,
    };
    ESP_ERROR_CHECK(adc_oneshot_new_unit(&unit_cfg, &handle));

    adc_oneshot_chan_cfg_t chan_cfg = {
        .atten    = ADC_ATTEN_DB_12,        // up to ~3.1 V, matches ADC_11db
        .bitwidth = ADC_BITWIDTH_12,        // 0–4095
    };
    ESP_ERROR_CHECK(adc_oneshot_config_channel(handle, FORCE_SENSOR_PIN, &chan_cfg));

    return handle;
}

/* ──────────────────────────────────────────────────────────────────── */
/*  PWM helper                                                          */
/* ──────────────────────────────────────────────────────────────────── */

static void set_pwm(int duty)   // duty: 0–255
{
    ESP_ERROR_CHECK(ledc_set_duty(LEDC_MODE, LEDC_CHANNEL, (uint32_t)duty));
    ESP_ERROR_CHECK(ledc_update_duty(LEDC_MODE, LEDC_CHANNEL));
}

/* ──────────────────────────────────────────────────────────────────── */
/*  Main task  (replaces loop())                                        */
/* ──────────────────────────────────────────────────────────────────── */

void app_main(void)
{
    gpio_init();
    ledc_pwm_init();
    adc_oneshot_unit_handle_t adc_handle = adc_init();

    bool break_flag = true;

    while (1) {
        /* ── 1. Read force sensor ──────────────────────────────────── */
        int analog_reading = 0;
        ESP_ERROR_CHECK(adc_oneshot_read(adc_handle, FORCE_SENSOR_PIN, &analog_reading));

        /* ── 2. Map ADC → PWM duty (0-4095 → 0-255) ───────────────── */
        int pwm_value = map_value(analog_reading, 0, ADC_MAX_RAW, 0, PWM_MAX_DUTY);
        pwm_value = constrain_value(pwm_value, 0, PWM_MAX_DUTY);

        /* ── 3. Button → relay + break_flag ───────────────────────── */
        if (gpio_get_level(BUTTON_IN_PIN) == 1) {
            gpio_set_level(RELAY_PIN, 0);   // LOW
            break_flag = false;
        } else {
            gpio_set_level(RELAY_PIN, 1);   // HIGH
            break_flag = true;
        }

        /* ── 4. Force threshold gate ───────────────────────────────── */
        if ((analog_reading <= FORCE_THRESHOLD) && break_flag) {
            gpio_set_level(DIGITAL_OUT_PIN, 0);
            set_pwm(0);
        } else {
            gpio_set_level(DIGITAL_OUT_PIN, 1);
            set_pwm(pwm_value);
        }

        /* ── 5. Serial logging ─────────────────────────────────────── */
        bool output_suppressed = (analog_reading <= FORCE_THRESHOLD) && break_flag;
        ESP_LOGI(TAG, "Force = %4d | PWM = %3d | OUT = %-4s | break_flag = %s",
                 analog_reading,
                 output_suppressed ? 0 : pwm_value,
                 output_suppressed ? "LOW" : "HIGH",
                 break_flag        ? "true" : "false");

        vTaskDelay(pdMS_TO_TICKS(20));  // 20 ms, same as Arduino delay(20)
    }
}

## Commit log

2026-04-07 feat(Software): Implemented a small state machine that would change based on force sensor and button to determine whether the car is in acceleration, braking, or cruise state
2026-04-07 docs(mech): added cad drawings, and restructred repo
    [Gear BIG2.step, Stand 2.step, smallgeartight.step]
2026-04-07 Paper Design Electronics
    [Paper_Design_Charging_Unit.kicad_sch]
2026-04-08 docs(elec): added images of circuit, restructured repo
    [Paper_Design_Charging_Unit.kicad_sch]
2026-04-15 fix(software): Altered braking mechanism
    [Small_State_Machine.ino]
2026-04-19 added BOM
